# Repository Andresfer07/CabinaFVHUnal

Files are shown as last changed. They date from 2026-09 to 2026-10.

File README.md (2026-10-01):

# CabinaFVHUnal

## 1. Descripción

Este repositorio contiene los archivos, diseños, datos y software desarrollados durante el proyecto **"Diseño e implementación de una cabina prototipo automatizada de bajo costo para la producción de Forraje Verde Hidropónico (FVH)"**.

El proyecto comprende el diseño y construcción de la cabina prototipo, los sistemas electrónicos y de control, el software de automatización, la interfaz de supervisión, AGRO-BOT, los diseños tridimensionales, los diseños de PCB, los datos de los ciclos de cultivo y el registro fotográfico del desarrollo del proyecto.

## 2. Recursos del proyecto

- **Video de funcionamiento:** [Ver video en YouTube](https://www.youtube.com/playlist?list=PLa2235HGgJpQ)
- **Dashboard remoto:** [Acceder al dashboard](https://cabinafvh.duckdns.org/dashboard/page1)
- **Repositorio complementario:** [Consultar archivos en Google Drive](https://drive.google.com/drive/folders/1n4Momb2bnFOUJLxZTVhM5PK6ztII8chc?usp=drive_link)

## 3. Organización del repositorio

La información se encuentra organizada en las siguientes carpetas:

- **Data Ciclos Cultivo:** datos registrados durante los ciclos experimentales, registros diarios y scripts de procesamiento y auditoría. Los archivos CSV consolidados de gran tamaño se conservan en Google Drive.
- **Diseños 3D:** modelos tridimensionales de la cabina, sus sistemas y componentes individuales. Los archivos F3D y STEP se conservan en Google Drive debido a su tamaño y características como archivos de diseño.
- **Interfaz Node-RED y AGRO-BOT:** archivos JSON correspondientes a los flujos de Node-RED y AGRO-BOT.
- **KiCad PCB:** proyectos de KiCad correspondientes a las PCB principal, de potencia y de sensores.
- **Python - Scripts de Control:** software de control ejecutado en la Raspberry Pi y archivos de datos utilizados por el sistema.
- **Registro Fotográfico:** registro visual de la construcción de la cabina y de los ciclos de cultivo. Las fotografías se conservan en el repositorio complementario de Google Drive debido a su tamaño.

Cada carpeta contiene un README específico con información sobre su contenido y organización.

## 4. Plataforma de control

El sistema de control fue implementado sobre una **Raspberry Pi 3B+**, utilizando Python como base para la ejecución de las funciones de automatización y control.

La arquitectura desarrollada también integra herramientas como Node-RED, Mosquitto e InfluxDB para las funciones de supervisión, comunicación y almacenamiento de información.

## 5. Reproducción de los archivos

Los archivos proporcionados permiten consultar y reproducir los diferentes desarrollos realizados durante el proyecto.

### Software de control

La estructura de la carpeta `Python - Scripts de Control` debe conservarse para mantener correctamente las relaciones entre el archivo principal y los módulos utilizados.

El archivo principal es:

```text
main2.py
```

Para ejecutar el sistema de control en la Raspberry Pi:

```bash
sudo python3 main2.py
```

Las dependencias de Python requeridas se encuentran especificadas en el archivo `requirements.txt` de la carpeta `Python - Scripts de Control`.

El uso de `sudo` es necesario debido a los requerimientos de acceso al hardware utilizados para el control de la iluminación mediante LEDs WS2812B.

### Flujos de Node-RED

Los flujos de Node-RED pueden reproducirse mediante la opción de **Importar** de Node-RED a partir de los archivos JSON proporcionados en `Interfaz Node-RED y AGRO-BOT`.

Los nodos de MQTT e InfluxDB requieren ajustar la dirección del broker y la base de datos según el entorno de ejecución (ver README de la carpeta `Interfaz Node-RED y AGRO-BOT`).

### Diseños 3D

Los modelos tridimensionales desarrollados durante el proyecto se encuentran disponibles en el repositorio complementario de Google Drive, cuyo enlace se encuentra en la sección **Recursos del proyecto**.

Los archivos F3D pueden abrirse y editarse mediante Autodesk Fusion 360. Los archivos STEP permiten la visualización e interoperabilidad de los modelos con otros programas de diseño asistido por computador.

### Diseños PCB

Los proyectos contenidos en `KiCad PCB` pueden abrirse mediante KiCad conservando los archivos propios de cada proyecto.

### Datos experimentales

Los archivos de `Data Ciclos Cultivo` contienen los registros diarios originales y los scripts utilizados para su procesamiento y auditoría.

Los archivos CSV consolidados de gran tamaño se conservan en el repositorio complementario de Google Drive, cuyo enlace se encuentra en la sección **Recursos del proyecto**.

### Registro Fotográfico

El registro fotográfico de la construcción de la cabina y de los ciclos de cultivo se encuentra disponible en el repositorio complementario de Google Drive, cuyo enlace se encuentra en la sección **Recursos del proyecto**.

## 6. Datos y documentación

Los datos, diseños y archivos de software contenidos en este repositorio corresponden a los desarrollos realizados durante el proyecto y constituyen el soporte técnico y experimental de la tesis.

La documentación se complementa con el documento de tesis, donde se presentan el diseño, implementación, metodología, validación y resultados obtenidos.

## 7. Requisitos generales

La reproducción completa del sistema físico requiere la plataforma de hardware y los componentes utilizados durante el desarrollo del prototipo.

Para la reproducción de los archivos digitales se requieren las herramientas correspondientes a cada tipo de recurso, entre ellas:

- Raspberry Pi OS y Python para el software de control.
- Node-RED para los flujos de supervisión y control.
- Mosquitto (broker MQTT) e InfluxDB para la comunicación y el almacenamiento de datos.
- KiCad para los diseños de PCB.
- Autodesk Fusion 360 u otro software compatible para los modelos 3D.
- Herramientas compatibles con archivos CSV y JSON para la consulta de datos.

## 8. Alcance

Este repositorio tiene como finalidad conservar y facilitar la consulta, trazabilidad y reproducción de los principales recursos desarrollados durante el proyecto de la cabina prototipo automatizada para producción de FVH.

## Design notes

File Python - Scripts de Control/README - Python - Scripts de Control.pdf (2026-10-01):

Python - Scripts de Control

### 1. Descripción

Esta carpeta contiene los scripts en Python desarrollados para el control y automatización de la cabina prototipo, junto con los archivos de configuración y almacenamiento de estados utilizados por el sistema.

### 2. Organización

La información se encuentra organizada de la siguiente manera:
Python - Scripts de Control/
├── main2.py

├── requirements.txt

├── Data/

│ ├── State.json

│ ├── Patterns.json

│ └── History.json

└── Control/

├── flowsensor.py

├── irrigationController.py

├── lightingController.py

├── Sensors.py

├── Settings.py

├── statemanager.py

├── ventilationController.py

└── WaterLevel.py

main2.py
Archivo principal encargado de iniciar y ejecutar el sistema de control desarrollado en Python.

requirements.txt
Lista las dependencias de Python necesarias para ejecutar el sistema de control. Data
Contiene los archivos JSON utilizados para almacenar información del sistema:
- State.json: almacena el estado actual del sistema.
- Patterns.json: contiene los patrones y configuraciones utilizados por el sistema.
- History.json: almacena el historial de información generado durante la operación.
Control
Contiene los módulos Python encargados de las diferentes funciones de control y adquisición del sistema:
- flowsensor.py: gestión del sensor de flujo.
- irrigationController.py: control del sistema de riego.
- lightingController.py: control del sistema de iluminación.
- Sensors.py: gestión de los sensores.
- Settings.py: parámetros y configuraciones del sistema.
- statemanager.py: gestión del estado del sistema.
- ventilationController.py: control del sistema de ventilación.
- WaterLevel.py: gestión de la medición del nivel de agua.

### 3. Uso de los archivos

Los scripts corresponden al software de control ejecutado en la Raspberry Pi y permiten implementar las funciones de automatización de la cabina prototipo. La estructura de carpetas se conserva de acuerdo con la organización utilizada durante la ejecución del sistema.
Antes de ejecutar el sistema, instalar las dependencias mediante:
pip3 install -r requirements.txt
Para iniciar el sistema de control:
sudo python3 main2.py

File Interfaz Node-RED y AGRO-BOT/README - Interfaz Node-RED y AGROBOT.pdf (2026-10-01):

Interfaz Node-RED y AGRO-BOT

### 1. Descripción

Esta carpeta contiene los archivos de configuración utilizados para la interfaz de supervisión y control de la cabina prototipo, así como para el funcionamiento de AGRO-BOT, desarrollados mediante Node-RED.

### 2. Contenido

- InterfazNode-RED: archivo JSON que contiene la configuración del flujo de la interfaz de supervisión, visualización y control de la cabina.
- AGRO-BOT: archivo JSON que contiene la configuración del flujo correspondiente al asistente AGRO-BOT desarrollado en Node-RED.

### 3. Uso de los archivos

Los archivos JSON permiten conservar y replicar los flujos desarrollados en Node-RED para la interfaz de supervisión y control y para el funcionamiento de AGRO-BOT.

Para importarlos en una instancia de Node-RED:

1. Abrir el menú (☰) → **Import**.
2. Seleccionar el archivo `.json` correspondiente.
3. Confirmar la importación.

### 4. Configuración de red (MQTT / InfluxDB)

Mosquitto e InfluxDB se ejecutan localmente en la Raspberry Pi de la cabina. El acceso remoto (incluyendo desde la instancia en OCI) se realiza mediante Tailscale, que asigna a la Raspberry Pi una IP privada (`100.82.96.70`) alcanzable desde cualquier dispositivo autenticado en la misma red Tailscale, sin requerir redirección de puertos ni una IP pública.
Para ejecutar el flujo en la misma Raspberry Pi sin pasar por Tailscale, los nodos de MQTT e InfluxDB deben apuntar a `localhost` (o `127.0.0.1`). Para acceder desde otro dispositivo de la misma red local, debe usarse la IP LAN asignada a la Raspberry Pi (ej. `192.168.x.x`).

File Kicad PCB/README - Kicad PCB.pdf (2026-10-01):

KiCad PCB

### 1. Descripción

Esta carpeta contiene los diseños de las tarjetas de circuito impreso (PCB) desarrolladas para la cabina prototipo automatizada, realizados mediante KiCad.

### 2. Organización

La información se encuentra organizada en tres carpetas, correspondientes a las PCB desarrolladas:
- FVHpcb optimizado: contiene el proyecto completo de KiCad correspondiente a la PCB principal de la cabina.
- Potencia: contiene el proyecto completo de KiCad correspondiente a la PCB de filtrado y protección de potencia para bombas, electroválvulas (EV) y luces LED.
- Sensores: contiene el proyecto completo de KiCad correspondiente a la PCB destinada a la conexión de los sensores.
Cada carpeta conserva los archivos necesarios del proyecto de KiCad para su consulta y edición.

### 3. Uso de los archivos

Los proyectos contenidos en esta carpeta corresponden a los diseños electrónicos desarrollados durante el proyecto y sirven como documentación del diseño de las tarjetas de circuito impreso utilizadas en la cabina prototipo.
Los proyectos pueden abrirse mediante KiCad, conservando la estructura de archivos propia de cada proyecto.

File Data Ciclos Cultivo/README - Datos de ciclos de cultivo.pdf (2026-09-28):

Datos de ciclos de cultivo

### 1. Descripción

Esta carpeta contiene los datos registrados durante los ciclos experimentales de producción de Forraje Verde Hidropónico (FVH) realizados mediante la cabina prototipo automatizada.

### 2. Organización de los datos

La información se encuentra organizada en dos carpetas, correspondientes a los ciclos de cultivo realizados:
- Data Ciclo 1
- Data Ciclo 2
Cada carpeta contiene los registros diarios del respectivo ciclo y los scripts empleados para su procesamiento y auditoría. Los archivos CSV consolidados de gran tamaño se conservan en Google Drive.
Data Ciclo 1
Contiene los archivos diarios correspondientes al periodo comprendido entre el 23 de junio y el 4 de julio de 2026.
Los archivos diarios siguen el formato:
cultivo_YYYY-MM-DD.csv
El archivo consolidado correspondiente es: cultivo_completo_2026-06-23_a_2026-07-04.csv Este archivo se encuentra disponible en Google Drive. Los scripts incluidos son:
- UnirCiclo1_csv
- AuditorCiclo1
Data Ciclo 2
Contiene los archivos diarios correspondientes al periodo comprendido entre el 27 de agosto y el 8 de septiembre de 2026.
Los archivos diarios siguen el formato:

cultivo_YYYY-MM-DD.csv
El archivo consolidado correspondiente es: cultivo_completo_2026-08-27_a_2026-09-08.csv Este archivo se encuentra disponible en Google Drive. Los scripts incluidos son:
- UnirCiclo2_csv
- AuditorCiclo2

### 3. Archivos CSV diarios

Cada archivo CSV contiene los datos registrados durante una jornada de operación de la cabina.
Estos archivos corresponden a los registros originales obtenidos durante la adquisición de datos y permiten conservar la información separada por fecha.

### 4. Archivos CSV consolidados

Para cada ciclo se dispone de un archivo CSV consolidado que reúne los registros diarios en un único archivo.
Debido a su tamaño, estos archivos se conservan en Google Drive y no se incluyen en el repositorio de GitHub.
Estos archivos facilitan el procesamiento, análisis y auditoría de la información correspondiente a cada ciclo completo.

### 5. Scripts de procesamiento

UnirCiclo
Los scripts UnirCiclo1_csv y UnirCiclo2_csv permiten unir los archivos CSV diarios correspondientes a cada ciclo en un único archivo consolidado.
Auditor
Los scripts AuditorCiclo1 y AuditorCiclo2 permiten realizar la auditoría de los datos registrados durante cada ciclo, verificando las condiciones de operación y facilitando el análisis de las variables de interés.

### 6. Uso de la información

Los datos contenidos en esta carpeta fueron utilizados para la evaluación de las condiciones de operación de la cabina durante los ciclos de cultivo y para el análisis de los resultados experimentales presentados en la tesis.
Se conservan los registros diarios, los archivos consolidados en Google Drive y los scripts de procesamiento y auditoría para mantener la trazabilidad y reproducibilidad del análisis.

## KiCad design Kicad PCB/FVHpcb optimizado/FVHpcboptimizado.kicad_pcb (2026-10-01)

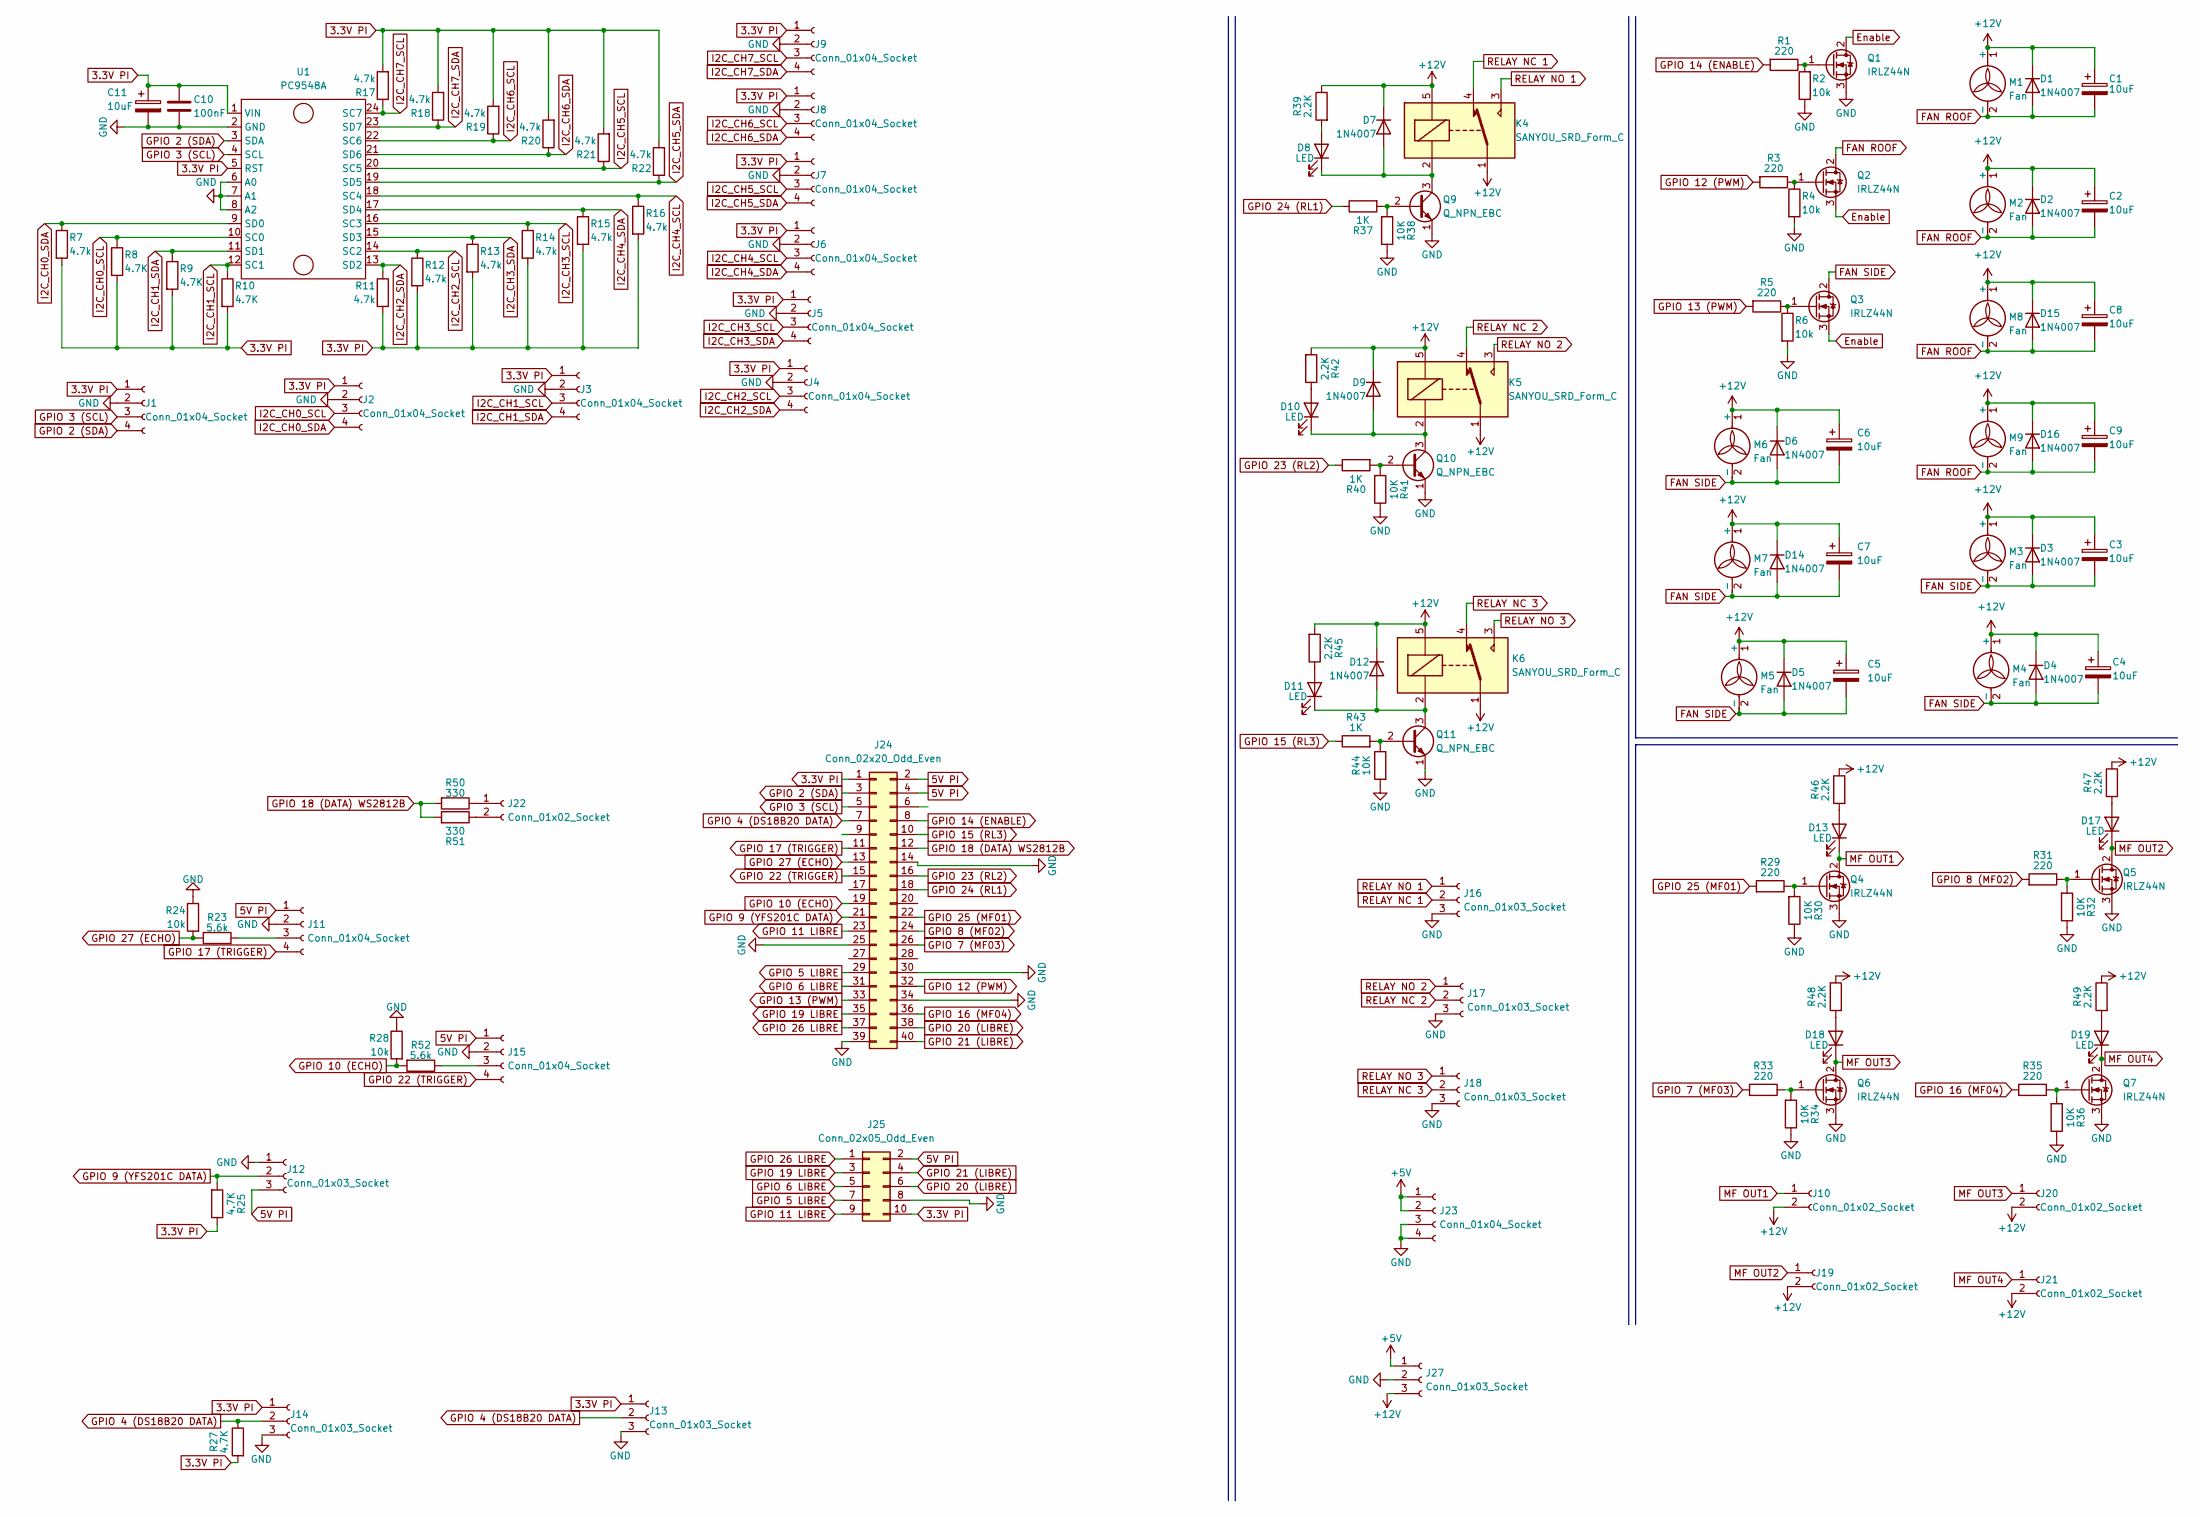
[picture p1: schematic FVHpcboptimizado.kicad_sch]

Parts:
C1, C2, C3, C4, C5, C6, C7, C8, C9, C11: 10uF; CP_Radial_D5.0mm_P2.00mm
C10: 100nF; C_Disc_D5.0mm_W2.5mm_P5.00mm
D1, D2, D3, D4, D5, D6, D7, D9, D12, D14, D15, D16: 1N4007; D_DO-41_SOD81_P10.16mm_Horizontal
D8, D10, D11, D13, D17, D18, D19: LED; LED_D3.0mm
J1, J2, J3, J4, J5, J6, J7, J8, J9, J11, J15: Conn_01x04_Socket; JST_XH_B4B-XH-A_1x04_P2.50mm_Vertical
J10, J19, J20, J21: Conn_01x02_Socket; TerminalBlock_Phoenix_MKDS-1,5-2_1x02_P5.00mm_Horizontal
J12, J13, J14: Conn_01x03_Socket; JST_XH_B3B-XH-A_1x03_P2.50mm_Vertical
J16, J17, J18: Conn_01x03_Socket; TerminalBlock_Phoenix_MKDS-1,5-3_1x03_P5.00mm_Horizontal
J22: Conn_01x02_Socket; TerminalBlock_Ningbo-Kagnex_HB9500M_1x02_P9.5mm
J23: Conn_01x04_Socket; TerminalBlock_Ningbo-Kagnex_HB9500M_1x04_P9.5mm
J24: Conn_02x20_Odd_Even; IDC-Header_2x20_P2.54mm_Vertical
J25: Conn_02x05_Odd_Even; PinHeader_2x05_P2.54mm_Vertical
J27: Conn_01x03_Socket; TerminalBlock_Ningbo-Kagnex_HB9500M_1x03_P9.5mm
K4, K5, K6: SANYOU_SRD_Form_C; Relay_SPDT_SANYOU_SRD_Series_Form_C
M1, M2, M3, M4, M5, M6, M7, M8, M9: Fan; Molex_KK-254_AE-6410-02A_1x02_P2.54mm_Vertical
Q1, Q2, Q3, Q4, Q5, Q6, Q7: IRLZ44N; TO-220-3_Vertical
Q9, Q10, Q11: Q_NPN_EBC; TO-92_Inline
R1, R3, R5, R29, R31, R33, R35: 220; R_Axial_DIN0207_L6.3mm_D2.5mm_P10.16mm_Horizontal
R2, R4, R6, R24, R28: 10k; R_Axial_DIN0207_L6.3mm_D2.5mm_P10.16mm_Horizontal
R7, R11, R12, R13, R14, R15, R16, R17, R18, R19, R20, R21, R22: 4.7k; R_Axial_DIN0207_L6.3mm_D2.5mm_P10.16mm_Horizontal
R8, R9, R10, R25, R27: 4.7K; R_Axial_DIN0207_L6.3mm_D2.5mm_P10.16mm_Horizontal
R23, R52: 5.6k; R_Axial_DIN0207_L6.3mm_D2.5mm_P10.16mm_Horizontal
R30, R32, R34, R36, R38, R41, R44: 10K; R_Axial_DIN0207_L6.3mm_D2.5mm_P10.16mm_Horizontal
R37, R40, R43: 1K; R_Axial_DIN0207_L6.3mm_D2.5mm_P10.16mm_Horizontal
R39, R42, R45, R46, R47, R48, R49: 2.2K; R_Axial_DIN0207_L6.3mm_D2.5mm_P10.16mm_Horizontal
R50, R51: 330; R_Axial_DIN0207_L6.3mm_D2.5mm_P10.16mm_Horizontal
U1: PC9548A; PC9548A_Morado

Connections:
3.3V PI: C10.1, C11.1, J1.1, J2.1, J3.1, J4.1, J5.1, J6.1, J7.1, J8.1, J9.1, J13.1, J14.1, J24.1, J25.10, R7.2, R8.2, R9.2, R10.2, R11.2, R12.2, R13.2, R14.2, R15.2, R16.2, R17.2, R18.2, R19.2, R20.2, R21.2, R22.2, R25.1, R27.2, U1.1 (VIN), U1.5 (RST)
5V PI: J11.1, J12.3, J15.1, J24.2, J24.4, J25.2
+5V: J23.1, J23.2, J27.1
+12V: C1.1, C2.1, C3.1, C4.1, C5.1, C6.1, C7.1, C8.1, C9.1, D1.1 (K), D2.1 (K), D3.1 (K), D4.1 (K), D5.1 (K), D6.1 (K), D7.1 (K), D9.1 (K), D12.1 (K), D14.1 (K), D15.1 (K), D16.1 (K), J10.2, J19.2, J20.2, J21.2, J27.3, K4.1, K4.5, K5.1, K5.5, K6.1, K6.5, M1.1 (+), M2.1 (+), M3.1 (+), M4.1 (+), M5.1 (+), M6.1 (+), M7.1 (+), M8.1 (+), M9.1 (+), R39.1, R42.2, R45.2, R46.1, R47.1, R48.1, R49.1
Enable: Q1.2 (D), Q2.3 (S), Q3.3 (S)
FAN ROOF: C1.2, C2.2, C8.2, C9.2, D1.2 (A), D2.2 (A), D15.2 (A), D16.2 (A), M1.2 (-), M2.2 (-), M8.2 (-), M9.2 (-), Q2.2 (D)
FAN SIDE: C3.2, C4.2, C5.2, C6.2, C7.2, D3.2 (A), D4.2 (A), D5.2 (A), D6.2 (A), D14.2 (A), M3.2 (-), M4.2 (-), M5.2 (-), M6.2 (-), M7.2 (-), Q3.2 (D)
GND: C10.2, C11.2, J1.2, J2.2, J3.2, J4.2, J5.2, J6.2, J7.2, J8.2, J9.2, J11.2, J12.1, J13.3, J14.3, J15.2, J16.3, J17.3, J18.3, J23.3, J23.4, J24.14, J24.25, J24.30, J24.34, J24.39, J25.8, J27.2, Q1.3 (S), Q4.3 (S), Q5.3 (S), Q6.3 (S), Q7.3 (S), Q9.1 (E), Q10.1 (E), Q11.1 (E), R2.1, R4.2, R6.2, R24.1, R28.1, R30.1, R32.1, R34.1, R36.1, R38.1, R41.1, R44.2, U1.2 (GND), U1.6 (A0), U1.7 (A1), U1.8 (A2)
GPIO 2 (SDA): J1.4, J24.3, U1.3 (SDA)
GPIO 3 (SCL): J1.3, J24.5, U1.4 (SCL)
GPIO 4 (DS18B20 DATA): J13.2, J14.2, J24.7, R27.1
GPIO 5 LIBRE: J24.29, J25.7
GPIO 6 LIBRE: J24.31, J25.5
GPIO 7 (MF03): J24.26, R33.2
GPIO 8 (MF02): J24.24, R31.2
GPIO 9 (YFS201C DATA): J12.2, J24.21, R25.2
GPIO 10 (ECHO): J24.19, R28.2, R52.2
GPIO 11 LIBRE: J24.23, J25.9
GPIO 12 (PWM): J24.32, R3.2
GPIO 13 (PWM): J24.33, R5.2
GPIO 14 (ENABLE): J24.8, R1.2
GPIO 15 (RL3): J24.10, R43.1
GPIO 16 (MF04): J24.36, R35.2
GPIO 17 (TRIGGER): J11.4, J24.11
GPIO 18 (DATA) WS2812B: J24.12, R50.2, R51.2
GPIO 19 LIBRE: J24.35, J25.3
GPIO 20 (LIBRE): J24.38, J25.6
GPIO 21 (LIBRE): J24.40, J25.4
GPIO 22 (TRIGGER): J15.4, J24.15
GPIO 23 (RL2): J24.16, R40.1
GPIO 24 (RL1): J24.18, R37.1
GPIO 25 (MF01): J24.22, R29.2
GPIO 26 LIBRE: J24.37, J25.1
GPIO 27 (ECHO): J24.13, R23.2, R24.2
I2C_CH0_SCL: J2.3, R8.1, U1.10 (SC0)
I2C_CH0_SDA: J2.4, R7.1, U1.9 (SD0)
I2C_CH1_SCL: J3.3, R10.1, U1.12 (SC1)
I2C_CH1_SDA: J3.4, R9.1, U1.11 (SD1)
I2C_CH2_SCL: J4.3, R12.1, U1.14 (SC2)
I2C_CH2_SDA: J4.4, R11.1, U1.13 (SD2)
I2C_CH3_SCL: J5.3, R14.1, U1.16 (SC3)
I2C_CH3_SDA: J5.4, R13.1, U1.15 (SD3)
I2C_CH4_SCL: J6.3, R16.1, U1.18 (SC4)
I2C_CH4_SDA: J6.4, R15.1, U1.17 (SD4)
I2C_CH5_SCL: J7.3, R21.1, U1.20 (SC5)
I2C_CH5_SDA: J7.4, R22.1, U1.19 (SD5)
I2C_CH6_SCL: J8.3, R19.1, U1.22 (SC6)
I2C_CH6_SDA: J8.4, R20.1, U1.21 (SD6)
I2C_CH7_SCL: J9.3, R17.1, U1.24 (SC7)
I2C_CH7_SDA: J9.4, R18.1, U1.23 (SD7)
MF OUT1: D13.1 (K), J10.1, Q4.2 (D)
MF OUT2: D17.1 (K), J19.1, Q5.2 (D)
MF OUT3: D18.1 (K), J20.1, Q6.2 (D)
MF OUT4: D19.1 (K), J21.1, Q7.2 (D)
unnamed: D7.2 (A), D8.1 (K), K4.2, Q9.3 (C)
unnamed: D8.2 (A), R39.2
unnamed: D10.2 (A), R42.1
unnamed: D9.2 (A), D10.1 (K), K5.2, Q10.3 (C)
unnamed: D11.2 (A), R45.1
unnamed: D11.1 (K), D12.2 (A), K6.2, Q11.3 (C)
unnamed: D13.2 (A), R46.2
unnamed: D17.2 (A), R47.2
unnamed: D18.2 (A), R48.2
unnamed: D19.2 (A), R49.2
unnamed: J11.3, R23.1
unnamed: J15.3, R52.1
unnamed: J22.1, R50.1
unnamed: J22.2, R51.1
unnamed: Q1.1 (G), R1.1, R2.2
unnamed: Q2.1 (G), R3.1, R4.1
unnamed: Q3.1 (G), R5.1, R6.1
unnamed: Q4.1 (G), R29.1, R30.2
unnamed: Q5.1 (G), R31.1, R32.2
unnamed: Q6.1 (G), R33.1, R34.2
unnamed: Q7.1 (G), R35.1, R36.2
unnamed: Q9.2 (B), R37.2, R38.2
unnamed: Q10.2 (B), R40.2, R41.2
unnamed: Q11.2 (B), R43.2, R44.1
RELAY NC 1: J16.2, K4.4
RELAY NC 2: J17.2, K5.4
RELAY NC 3: J18.2, K6.4
RELAY NO 1: J16.1, K4.3
RELAY NO 2: J17.1, K5.3
RELAY NO 3: J18.1, K6.3

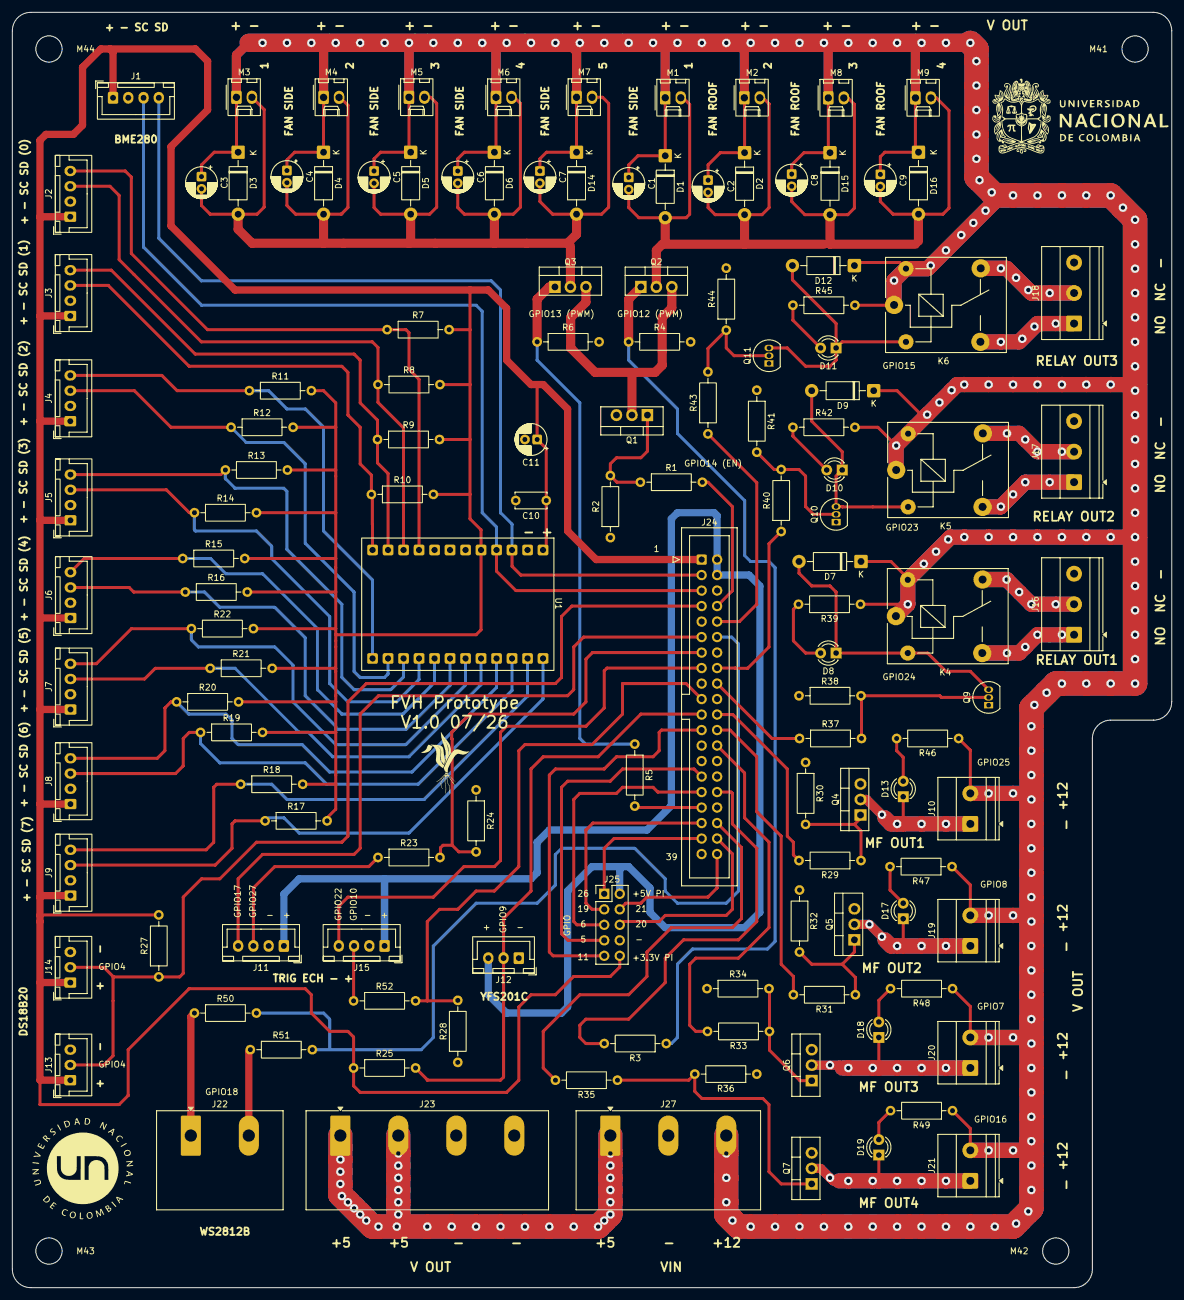
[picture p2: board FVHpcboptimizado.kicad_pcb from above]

Board: 2 copper layers, 190.0 x 209.0 mm, 134 parts (0 on the bottom side), 84 nets.

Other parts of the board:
M41, M42, M43, M44: MountingHole_4.3mm_M4

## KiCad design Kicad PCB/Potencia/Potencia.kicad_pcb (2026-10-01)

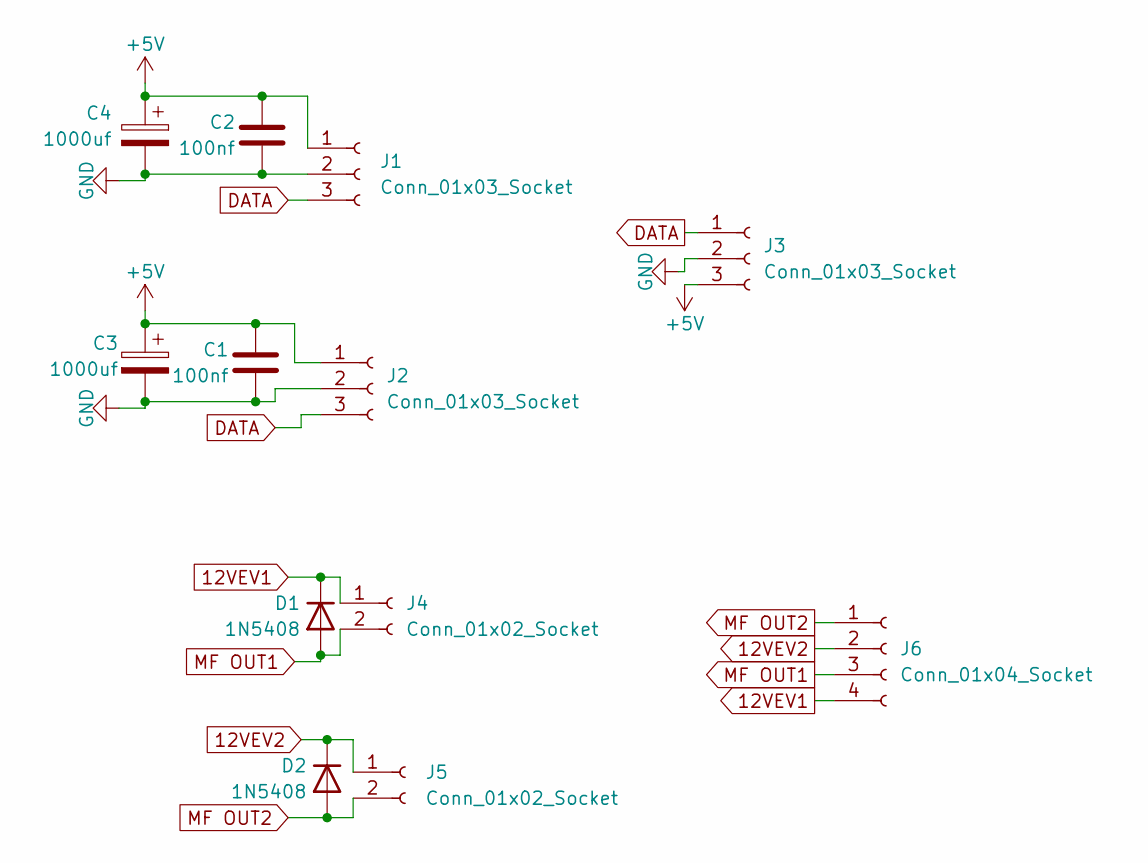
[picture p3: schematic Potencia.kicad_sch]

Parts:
C1, C2: 100nf; C_Disc_D5.0mm_W2.5mm_P2.50mm
C3, C4: 1000uf; CP_Radial_D13.0mm_P5.00mm
D1, D2: 1N5408; D_DO-201AD_P15.24mm_Horizontal
J1, J2: Conn_01x03_Socket; PhoenixContact_MSTBVA_2,5_3-G-5,08_1x03_P5.08mm_Vertical
J3: Conn_01x03_Socket; PhoenixContact_GMSTBVA_2,5_3-G-7,62_1x03_P7.62mm_Vertical
J4, J5: Conn_01x02_Socket; PhoenixContact_MSTBVA_2,5_2-G-5,08_1x02_P5.08mm_Vertical
J6: Conn_01x04_Socket; PhoenixContact_GMSTBVA_2,5_4-G-7,62_1x04_P7.62mm_Vertical

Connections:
12VEV1: D1.1 (K), J4.1, J6.4
12VEV2: D2.1 (K), J5.1, J6.2
+5V: C1.1, C2.1, C3.1, C4.1, J1.1, J2.1, J3.3
DATA: J1.3, J2.3, J3.1
GND: C1.2, C2.2, C3.2, C4.2, J1.2, J2.2, J3.2
MF OUT1: D1.2 (A), J4.2, J6.3
MF OUT2: D2.2 (A), J5.2, J6.1

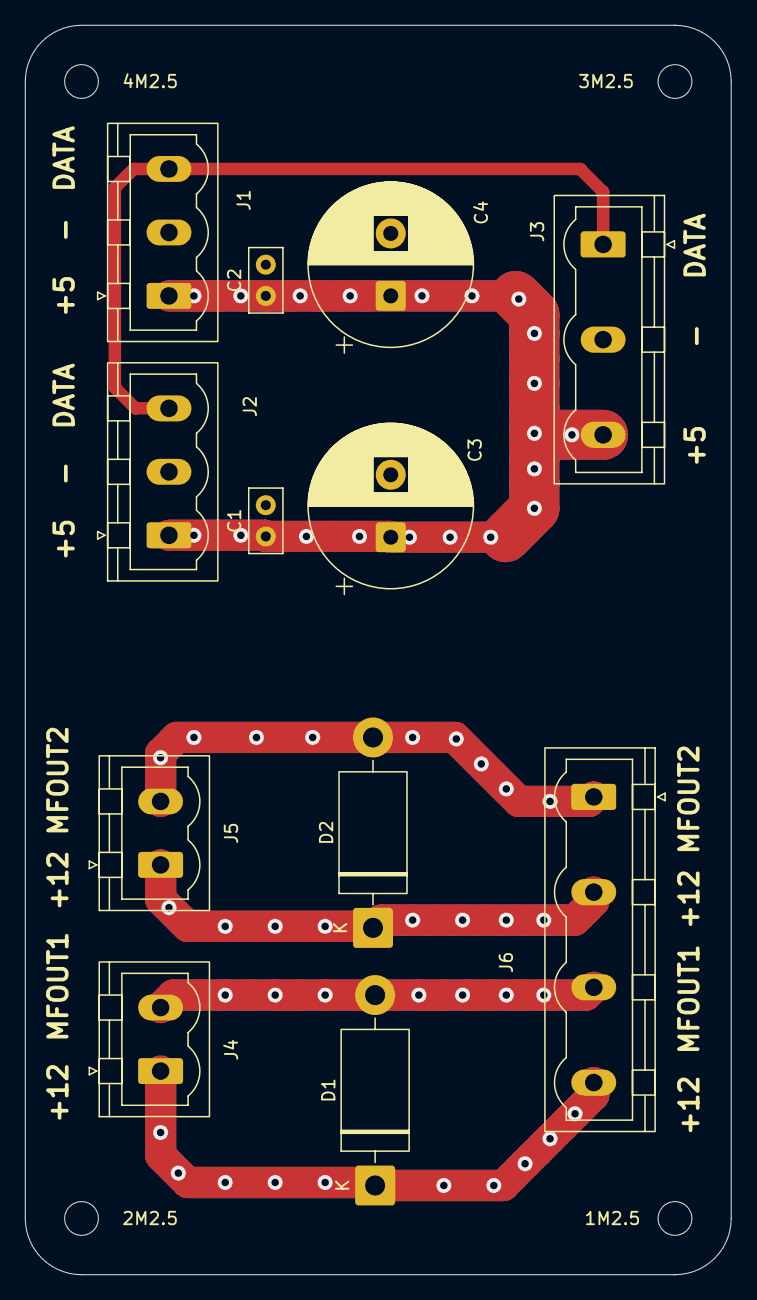
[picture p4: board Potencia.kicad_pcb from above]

Board: 2 copper layers, 56.5 x 100.0 mm, 16 parts (0 on the bottom side), 7 nets.

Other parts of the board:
1M2.5, 2M2.5, 3M2.5, 4M2.5: MountingHole_2.7mm_M2.5

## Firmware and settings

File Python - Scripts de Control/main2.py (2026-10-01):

# Main.py → VERSIÓN CORREGIDA - CABINA FVH 2025
import time
import json
from datetime import datetime
import paho.mqtt.client as mqtt
import numpy as np
import RPi.GPIO as GPIO
import os
import threading
import sys
import signal


# Controladores
from Control.irrigationController import (
    run_scheduler as irr_run, 
    emergency_irrigation_if_needed,     
    irr_clear,
    get_duration_today,
    setup_irrigation,
    sync_completed_riego,
    manual_on,
    manual_off,
    handle_tank_state,
    manual_mixer_on,
    manual_mixer_off,
    handle_pressurize_mode,
    retry_pressurization
)
from sdnotify import SystemdNotifier
from Control.lightingController import update_lighting
from Control.ventilationController import (
    update_ventilation, clear as vent_clear, disable_all
)
from Control import Sensors
from Control.Sensors import read_all
from Control.WaterLevel import get_water_level_percent, wl_clear
from Control.statemanager import ( 
    get_state, update_state, log_event, 
    log_sensors, get_pattern, get_cycle, 
    update_state_in_memory, get_all_patterns, 
    delete_pattern, set_state, add_pattern, reset_cycle
)
from Control.Settings import LED_BRIGHTNESS

# MQTT Setup
client = mqtt.Client(
     client_id="CabinaFVH_Main",
     callback_api_version=mqtt.CallbackAPIVersion.VERSION1
)

client.connect("localhost", 1883, 60)
client.loop_start()
notifier = SystemdNotifier()

def graceful_shutdown(signum, frame):
    print("\nSIGTERM recibido → cerrando limpio...")

    try:
        update_state("system", "dirty_shutdown", False)

        # FORZAR escritura inmediata
        state = get_state()
        set_state(state)

    except Exception as e:
        print(f"Error guardando shutdown limpio: {e}")

    try:
        irr_clear()
        disable_all()
        wl_clear()

        client.loop_stop()
        client.disconnect()

        GPIO.cleanup()

    except Exception as e:
        print(f"Error cleanup: {e}")

    print("Shutdown limpio completado.")
    os._exit(0)



def calculate_vpd(temp_c, rh_percent):
    es = 0.6108 * np.exp((17.27 * temp_c) / (temp_c + 237.3))
    ea = es * (rh_percent / 100.0)
    return round(es - ea, 3)

def is_time_in_range(start, end, now):
    if start <= end:
        return start <= now <= end
    else:
        return now >= start or now <= end

def publish_all(sensors=None):
    """Lee sensores y envía telemetría completa a Node-RED y ThingsBoard."""
    try:

        sensors = sensors if sensors is not None else read_all()
        state = get_state()
        water = state.get("irrigation", {}).get("water_level", -1)

        irrigation_state = state.get("irrigation", {})
        lighting_state = state.get("lighting", {})
        ventilation_state = state.get("ventilation", {})
        system_state = state.get("system", {})


        irrigation_alarms = irrigation_state.get("alarms", {})
        ventilation_alarms = ventilation_state.get("alarms", {})
        lighting_alarms = lighting_state.get("alarms", {})

        alarms = {
            #Irrigation
            "low_water": irrigation_alarms.get("tank_low", False),
            "pressure_fail": irrigation_alarms.get("pressurize_failed", False),
            "blocked": irrigation_state.get("force_off", False),
            "emergency_irrigation_event": irrigation_alarms.get("emergency_heat", False),
            "restart": irrigation_alarms.get("power_loss", False),
            "water_level_error": irrigation_alarms.get("sensor_error", False),
            "flow_error": irrigation_alarms.get("flow_error", False),

            #Ventilation
            "overheat": ventilation_alarms.get("overheat", False),
            "humidity_critical": ventilation_alarms.get("humidity_critical", False),
            "tempandhumid_error": ventilation_alarms.get("sensor_error", False),

            #VPD
            "temp_vpd_error": not Sensors._ds18b20_ok,

            #Lighting
            "lighting_fail": lighting_alarms.get("fail", False),
            "lighting_pattern_error": lighting_alarms.get("pattern_error", False),
            "lighting_config_error": lighting_alarms.get("config_error", False),

        }

        # Sistema normal irrigation
        irrigation_system_ok = not any([
            alarms["pressure_fail"],
            alarms["low_water"],
            alarms["blocked"],
            alarms["restart"],
            alarms["water_level_error"],
            alarms["flow_error"]
        ])

        # Clima normal ventilation
        
        climate_ok = not any ([
            alarms["overheat"],
            alarms["humidity_critical"],
            alarms["tempandhumid_error"],
        ])

        # Sistema normal Luz

        light_system_ok = not any([
            alarms["lighting_fail"],
            alarms["lighting_pattern_error"],
            alarms["lighting_config_error"],
        ])
  
        # habitat_ok REAL
        habitat_ok = irrigation_system_ok and climate_ok and light_system_ok


        #t_in = (sensors["htu21d"]["sda0_temp"] + sensors["htu21d"]["sda1_temp"]) / 2
        #h_in = (sensors["htu21d"]["sda0_hum"] + sensors["htu21d"]["sda1_hum"]) / 2
        t_in = sensors["htu21d"]["sda1_temp"]
        h_in = sensors["htu21d"]["sda1_hum"]
        t_ds = sensors["ds18b20"]["temperature"]
        t_target = t_ds if Sensors._ds18b20_ok else t_in
        vpd = calculate_vpd(t_target, h_in)

        irrigation_state = state.get("irrigation", {})
        #print(f"[VALVES STATE] {irrigation_state.get('valves')}")
        #print(f"[PUMP STATE] {irrigation_state.get('pump')}")
        #print(f"[IRRIGATION ACTIVE] {irrigation_state.get('irrigation_active')}")
        lighting_state = state.get("lighting", {})
        ventilation_state = state.get("ventilation", {})
        vent_config = ventilation_state.get("config") or {}

        payload = {
            "ts": int(time.time() * 1000),
            "values": {
                "temp_in": round(t_in, 2), 
                #"temp_out": round(sensors["bme280"]["temperature"], 2),
                "temp_out": round(sensors["htu21d"]["sda0_temp"], 2),
                "hum_in": round(h_in, 2), 
                #"hum_out": round(sensors["bme280"]["humidity"], 2),
                "hum_out": round(sensors["htu21d"]["sda0_hum"], 2),
                "vpd_kpa": vpd, 
                "water_level": water, 
                "day": irrigation_state.get("current_day", 1),
                "irrigation_mode": irrigation_state.get("mode", "manual"),
                "pump": irrigation_state.get("pump", 0),         
                "valve_1": irrigation_state.get("valves", [0,0])[0],
                "valve_2": irrigation_state.get("valves", [0,0])[1],
                "lighting_mode": lighting_state.get("mode", "auto"),
                "ventilation_mode": ventilation_state.get("mode", "auto"),
                "roof_fan": ventilation_state.get("roof_duty", 0),
                "side_fan": ventilation_state.get("side_duty", 0),
                "progreso_riego": irrigation_state.get("completed_today", []),
                "duracion_programada": get_duration_today(),
                "last_programmed": irrigation_state.get("last_programmed"),
                "last_emergency": irrigation_state.get("last_emergency"),
                "pressurized_once": irrigation_state.get("pressurized_once", False),
                "lighting_pattern": lighting_state.get("pattern") or "default",
                "remaining_seconds": irrigation_state.get("remaining_seconds", 0),
                "irrigation_active": irrigation_state.get("irrigation_active", False),
                "irrigation_times": str(",".join(irrigation_state.get("irrigation_times", []))),
                "alarm_low_water": alarms["low_water"],
                "alarm_pressure_fail": alarms["pressure_fail"],
                "alarm_blocked": alarms["blocked"],
                "emergency_irrigation_event": alarms["emergency_irrigation_event"],
                "alarm_restart": alarms["restart"],
                "alarm_system_normal": irrigation_system_ok,
                "alarm_water_level_error": alarms["water_level_error"],
                "pressurize_time": irrigation_state.get("config", {}).get("pressurize_time"),
                "temp_emergency": irrigation_state.get("config", {}).get("temp_emergency"),
                "time_irrigation_emergency": irrigation_state.get("config", {}).get("time_irrigation_emergency"),
                "lighting_colors": json.dumps(lighting_state.get("colors") or []),
                "lighting_brightness": lighting_state.get("brightness"),
                "lighting_enabled": lighting_state.get("enabled", False),
                "duration_per_day": ",".join(map(str, irrigation_state.get("duration_per_day", []))),
                "temp_low": vent_config.get("temp_low"),
                "temp_medium": vent_config.get("temp_medium"),
                "temp_high": vent_config.get("temp_high"),
                "humidity_low": vent_config.get("humidity_low"),
                "humidity_medium": vent_config.get("humidity_medium"),
                "humidity_high": vent_config.get("humidity_high"),
                "delta_low_t": vent_config.get("delta_low_t"),
                "delta_high_t": vent_config.get("delta_high_t"),
                "delta_temp": round(sensors["htu21d"]["sda1_temp"] - sensors["htu21d"]["sda0_temp"],2),
                "alarm_overheat": alarms["overheat"],
                "alarm_humidity_critical": alarms["humidity_critical"],
                "alarm_tempandhumid_error": alarms["tempandhumid_error"],
                "alarm_lighting_fail": alarms["lighting_fail"],
                "alarm_lighting_pattern_error": alarms["lighting_pattern_error"],
                "alarm_lighting_config_error": alarms["lighting_config_error"],
                "alarm_climate_ok": climate_ok,
                "alarm_light_ok": light_system_ok,
                "alarms_habitat_ok": habitat_ok,
                "lighting_schedule": json.dumps(lighting_state.get("schedule", {})),
                "flow_error": irrigation_alarms.get("flow_error", False),
                "cycle_status": system_state.get("cycle_status"),
                "mixer": irrigation_state.get("mixer", 0),
                "delta_hum" : round(sensors["htu21d"]["sda1_hum"] - sensors["htu21d"]["sda0_hum"], 2),
                "delta_low_h": vent_config.get("delta_low_h"),
                "delta_high_h": vent_config.get("delta_high_h"),
                "alarm_temp_vpd_error": alarms["temp_vpd_error"],
                "water_manual_liters": irrigation_state.get("water_manual_liters", 0.0),
                "water_pressurization_liters": irrigation_state.get("water_pressurization_liters", 0.0),
                "water_programmed_liters": irrigation_state.get("water_programmed_liters", 0.0),
                "water_emergency_liters": irrigation_state.get("water_emergency_liters", 0.0),
                "water_total_auto_liters": irrigation_state.get("water_total_auto_liters", 0.0),
                "water_cycle_total_liters": irrigation_state.get("water_cycle_total_liters", 0.0),

            }
        }
        #Modificar campos None or null
        payload["values"] = {k: v for k, v in payload["values"].items() if v is not None}

        client.publish("v1/devices/me/telemetry", json.dumps(payload))
        client.publish("cabin/telemetry", json.dumps(payload)) 
        log_sensors(sensors)
    except Exception as e:
        log_event("main", "publish_error", {"error": str(e)})


def on_message(c, u, msg):
    try:
        data = json.loads(msg.payload.decode())
        updates_applied = 0
        state = get_state()
        batch_mode = True

        # -------------------------
        # DELETE PATTERN
        # -------------------------
        if "delete_pattern" in data:

            name = data.get("delete_pattern")
            delete_pattern(name)

            #  LIMPIAR ESTADO SI ELIMINAS EL ACTIVO
            lighting_state = state.get("lighting", {})
            current_pattern = lighting_state.get("pattern")

            if current_pattern == name:
                print(f" Eliminando patrón activo '{name}' → aplicando default")

                default_pattern = get_pattern("default")

                if not default_pattern:

                    default_pattern = {"colors": [[0, 0, 0]],"brightness": 255}

                state = update_state_in_memory(state, "lighting", "pattern", "default")
                state = update_state_in_memory(state, "lighting", "colors", default_pattern.get("colors", []))
                state = update_state_in_memory(state, "lighting", "brightness", default_pattern.get("brightness", 255))
                state = update_state_in_memory(state, "lighting", "save_as", None)
            
            set_state(state)

            patterns = get_all_patterns()
            client.publish("cabin/patterns", json.dumps(patterns))
            print(f" Patrón '{name}' eliminado correctamente")
            return

        # -------------------------
        # GET ALL PATTERNS
        # -------------------------
        if "get_patterns" in data:

            patterns = get_all_patterns()
            client.publish("cabin/patterns", json.dumps(patterns))
            print(f" Enviando {len(patterns)} patrones")
            return

        # -------------------------
        # GET ONE PATTERN
        # -------------------------
        if "get_pattern" in data:

            name = data.get("get_pattern")

            if not name:
                print(" get_pattern recibió None → ignorado")
                return 

            pattern_data = get_pattern(name)

            if pattern_data:
                client.publish("cabin/pattern_data", json.dumps({
                    "name": name,
                    "colors": pattern_data.get("colors", []),
                    "brightness": pattern_data.get("brightness", 255)
                }))
            else:
                print(f" Patrón '{name}' no encontrado")

            return

        # -------------------------
        # PROCESAMIENTO GENERAL
        # -------------------------
        for section, values in data.items():

            if not isinstance(values, dict) or section not in ["irrigation", "lighting", "ventilation", "system"]:
                continue

            # =========================================
            # FINALIZACION DE CICLO Y REINICIO MANUAL
            # =========================================

            if section == "system":

                # APAGADO
                if values.get("shutdown") is True:
                    shutdown_system()
                    return

                if values.get("reset_cycle") is True:
                    print(" RESET DE CICLO SOLICITADO")
                    if reset_cycle():
                        # 1. Limpieza lógica de controladores
                        irr_clear()
                        disable_all()
                        #clear()
                        #2. Forzar actualización física inmediata
                        update_state("irrigation", "irrigation_active", False)
                        update_state("irrigation", "remaining_seconds", 0)
                        update_lighting()
                        update_ventilation()
                        #3. Informar a Node-RED del nuevo estado (idle)
                        publish_all() 
                        print(" >>> RESET EXITOSO: Hardware apagado y telemetría enviada.")
                        
                    return

                # CAMBIO DE ESTADO GLOBAL
                if "cycle_status" in values:
                    new_status = values["cycle_status"]
                    # Usamos update_state para que dispare la lógica de protección/modos
                    update_state("system", "cycle_status", new_status)
                    # Recargamos el state local para que el batch_mode no lo sobrescriba
                    state = get_state() 
                    print(f" cycle_status → {new_status} (Modos reseteados si es STOP)")
                    
            # =========================================
            #  FIX BRILLO (CRÍTICO)
            # =========================================
            if section == "lighting":

                # 1. Aplicar brightness primero SI existe
                if "brightness" in values:
                    state = update_state_in_memory(state, "lighting", "brightness", values["brightness"])
                    updates_applied += 1


                # 2. Luego procesar el resto
                for k, v in values.items():
                    
                    if k == "brightness":
                        continue
                    if v is None:
                        continue

                    if k == "schedule":
                        # LIMPIEZA AUTOMÁTICA
                        for day, cfg in v.items():
                            if cfg.get("enabled") is False:
                                cfg.pop("start", None)
                                cfg.pop("end", None)
                        state = update_state_in_memory(state, "lighting", "schedule", v)
                        print(" Schedule actualizado")
                        continue

                    if k == "enabled":
                        state = update_state_in_memory(state, "lighting", "enabled", v)
                        continue

                    if k == "colors":
                        state = update_state_in_memory(state, "lighting", "colors", v)
                        if "pattern" not in values:
                             state = update_state_in_memory(state, "lighting", "pattern", "colormanual")
                        

                    if k == "pattern":

                        if not v:
                            print(" pattern vacío → usando default")
                            v = "default"
                            
                        pattern_data = get_pattern(v)
                        
                        if not pattern_data:
                            print(f" Patrón '{v}' no existe → usando default")
                            v = "default"
                            pattern_data = get_pattern("default")

                        if not pattern_data:
                            pattern_data = {
                            "colors": [[0, 0, 0]],
                            "brightness": 255
                            }

                        update_state("lighting", "pattern", v)
                        state = get_state()
                        state = update_state_in_memory(state, "lighting", "colors", pattern_data.get("colors", []))
                        state = update_state_in_memory(state, "lighting", "brightness", pattern_data.get("brightness", 255))
                        state = update_state_in_memory(state, "lighting", "save_as", None)


                        continue

                    if k == "save_as":
                        add_pattern(v,state.get("lighting", {}).get("colors"),state.get("lighting", {}).get("brightness", 255))
                        state = update_state_in_memory(state, "lighting", "pattern", v)
                        state = update_state_in_memory(state, "lighting", "save_as", None)
                        patterns = get_all_patterns()
                        client.publish("cabin/patterns", json.dumps(patterns))
                        print(f" Patrón '{v}' guardado correctamente")
                        continue
                

                    updates_applied += 1

                continue  #  NO bajar al bloque general

            # =========================================
            # RESTO: irrigation + ventilation
            # =========================================

            if section == "irrigation":
                #Reintento de presurizacion
                    if "retry_pressurization" in values:
                            if values.get("retry_pressurization") is True:
                                    result = retry_pressurization()
                                    if result:
                                             print(" >>> REINTENTO DE PRESURIZACIÓN ACEPTADO")
                                    else:
                                            print(" >>> REINTENTO DE PRESURIZACIÓN RECHAZADO")
                            continue
                #Irrigation Manual 
                    if "manual_on" in values:
                        seconds = values.get("seconds")
                        #manual_on(seconds)
                        thread_riego = threading.Thread(target=manual_on, args=(seconds,))
                        thread_riego.start()
                        continue

                    if "manual_off" in values:
                        manual_off()
                        state = get_state()  
                        continue

                #Mezclado Manual
                    if "manual_mixer_on" in values:
                        secondsmixer = values.get("secondsmixer")
                        manual_mixer_on(secondsmixer)
                        continue

                    if "manual_mixer_off" in values:
                        manual_mixer_off()
                        continue
            
                    
            for k, v in values.items():

                if v is None:
                    continue

                # ---- IRRIGATION TIMES ----
                if section == "irrigation" and k == "irrigation_times":

                    if isinstance(v, str):
                        v = [t.strip() for t in v.split(",") if t.strip()]

                    if isinstance(v, list):
                        now_dt = datetime.now()
                        #update_state("irrigation", "irrigation_times", v)
                        state = update_state_in_memory(state, "irrigation", "irrigation_times", v)
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

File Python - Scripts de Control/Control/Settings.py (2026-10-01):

# settings.py
from pathlib import Path

# --- Rutas base ---
BASE_DIR = Path(__file__).resolve().parent
DATA_DIR = BASE_DIR / "Data"

STATE_FILE   = DATA_DIR / "State.json"
PATTERNS_FILE = DATA_DIR / "Patterns.json"

# --- LISTADO DE PINES GPIO (NUMERACIÓN BCM) ---
LED_PIN       = 18
PIN_YFS201    = 9
PIN_FAN1      = 13
PIN_FAN2      = 12
PIN_ENABLE    = 14
I2C_SCL       = 'board.SCL'
I2C_SDA       = 'board.SDA'
PIN_DS18B20   = 4
PIN_ECHO      = 10
PIN_ECHO2     = 27
PIN_TRIGGER   = 22
PIN_TRIGGER2  = 17
PIN_EVALVE1   = 25
PIN_EVALVE2   = 16
PIN_PUMP      = 15
PIN_MIXER     = 24

# --- SENSORES ---
#BME280_ADDRESS      = 0x76
#BMELEVELPRESSURE    = 1015.0  # presión a nivel del mar de Florencia - Caquetá (Colombia)

# HC-SR04
SAMPLES        = 7         # número de mediciones por ciclo (impar para mediana)
TIME_BETWEEN   = 0.06      # tiempo entre ciclos
TIMEOUT        = 0.03      # timeout para flancos (segundos)
MIN_DIST_CM    = 2.0       # distancia mínima fiable
MAX_DIST_CM    = 400.0     # distancia máxima teórica
TANK_HEIGHT_CM = 38      # altura máxima del tanque
MIN_LEVEL_SAFE = 20        # bajo este % bloqueamos riego (seguridad bomba)


# YFS201 (sensor de flujo)
CALIBRATION_FACTOR = 7.5   # 7.5 pulsos/s ≈ 1 L/min
MIN_FLOW_PULSES = 5  # ajustar empírico
FLOW_CHECK_DELAY = 3 

# --- ACTUADORES ---

# Ventiladores
PWM_FREQ = 60  # PWM Hz
MAX_DUTY = 100    # porcentaje máximo
MIN_DUTY = 30    # porcentaje mínimo

# LEDs (NeoPixel WS2812B)
LED_COUNT      = 150    # Número total de LEDs
LED_FREQ_HZ    = 800000 # Frecuencia de la señal LED en Hz (normalmente 800 kHz)
LED_DMA        = 10     # Canal DMA para generar señal
LED_BRIGHTNESS = 255    # Brillo inicial por defecto (0-255)
LED_INVERT     = False  # True si usas un transistor NPN
LED_CHANNEL    = 0      # 1 si se usan GPIO 13, 19, 41, 45 o 53

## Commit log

2026-09-28 Agregar datos de ciclos de cultivos
    [cultivo_2026-06-23.csv, cultivo_2026-06-24.csv, cultivo_2026-06-25.csv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]
2026-10-01 Actualización kicadpcb
    [FVHpcboptimizado.kicad_pcb, FVHpcboptimizado.kicad_sch, Potencia.kicad_pcb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]
